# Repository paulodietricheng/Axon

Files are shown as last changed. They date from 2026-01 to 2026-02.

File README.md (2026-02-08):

# Axon

Axon is a single-channel mixed-signal Electromyography (EMG) acquisition and actuation system built around a custom PCB. It combines a low-noise analog front end, delta-sigma analog-to-digital conversion, and STM32 firmware for real-time signal acquisition and control of external devices.

The project emphasizes signal integrity, deterministic signal paths, and hardware/firmware co-design in a timing-constrained embedded system.

## System Architecture
Axon implements a linear signal-processing pipeline from electrodes to digital processing:

- Electrodes  
- Input Protection  
- Instrumentation Amplifier  
- Active Band-Pass Filtering  
- Delta-Sigma ADC  
- STM32 (SPI)  
- Actuation Outputs

## Analog Front End

### Input Protection
- 100 kΩ series resistor at the electrode input
- Schottky diode clamps to +5 V and −5 V
- Protects downstream circuitry from transients and overvoltage events

### Instrumentation Amplifier
- INA333 instrumentation amplifier
- Gain: 20×
- Chosen for high CMRR (~100 dB) to suppress common-mode noise inherent in EMG signals
- Reference voltage provided by a buffered ground generated using an OPA333

### Active Filtering
All active filters use OPA333 op-amps for low offset and low noise.

- High-pass Sallen–Key filter  
  - Cutoff frequency: 15 Hz  
  - Linear gain  
  - Removes DC offset and motion artifacts

- Low-pass Sallen–Key filter  
  - Cutoff frequency: 450 Hz
  - Gain: 5×
  - Limits high-frequency noise and out-of-band content

## Analog-to-Digital Conversion

- ADS131M02 delta-sigma ADC
- Differential inputs:
  - Filtered signal routed through 1 kΩ resistors to AIN0P and AIN1P
  - AIN0N and AIN1N tied to buffered ground
- ADC clock provided by an ASE 8.192 MHz oscillator
- Design considers conversion latency and group delay inherent to delta-sigma architectures

## Digital Processing & Control

### Microcontroller
- STM32 microcontroller
- Communicates with ADC via SPI
- Handles data acquisition, processing, and output control

### Programming & Debug
- JTAG / SWD interface exposed
- Signals:
  - SWDIO, SWCLK, SWO, RESET
  - RXI, TXO
  - VREF = 3.3 V

### Outputs
- Three MCU-controlled output pins routed to an external connector
- Intended for actuation or control of external devices

## Power Architecture

- USB-C power input
- Protection fuse on input
- Power rails:
  - +5 V from USB
  - −5 V generated via TPS7A inverter
  - 3.3 V generated via TPS604 DC-DC converter

## PCB Layout

- 4-layer PCB stackup:
  1. Signal
  2. Ground plane
  3. Power pours
  4. Signal
- Layout prioritizes:
  - Low-noise analog routing
  - Solid ground reference
  - Separation of analog and digital domains

## Notes

Axon serves as a completed mixed-signal system demonstrating practical considerations in low-level analog design, real-time embedded firmware, and end-to-end signal path analysis.

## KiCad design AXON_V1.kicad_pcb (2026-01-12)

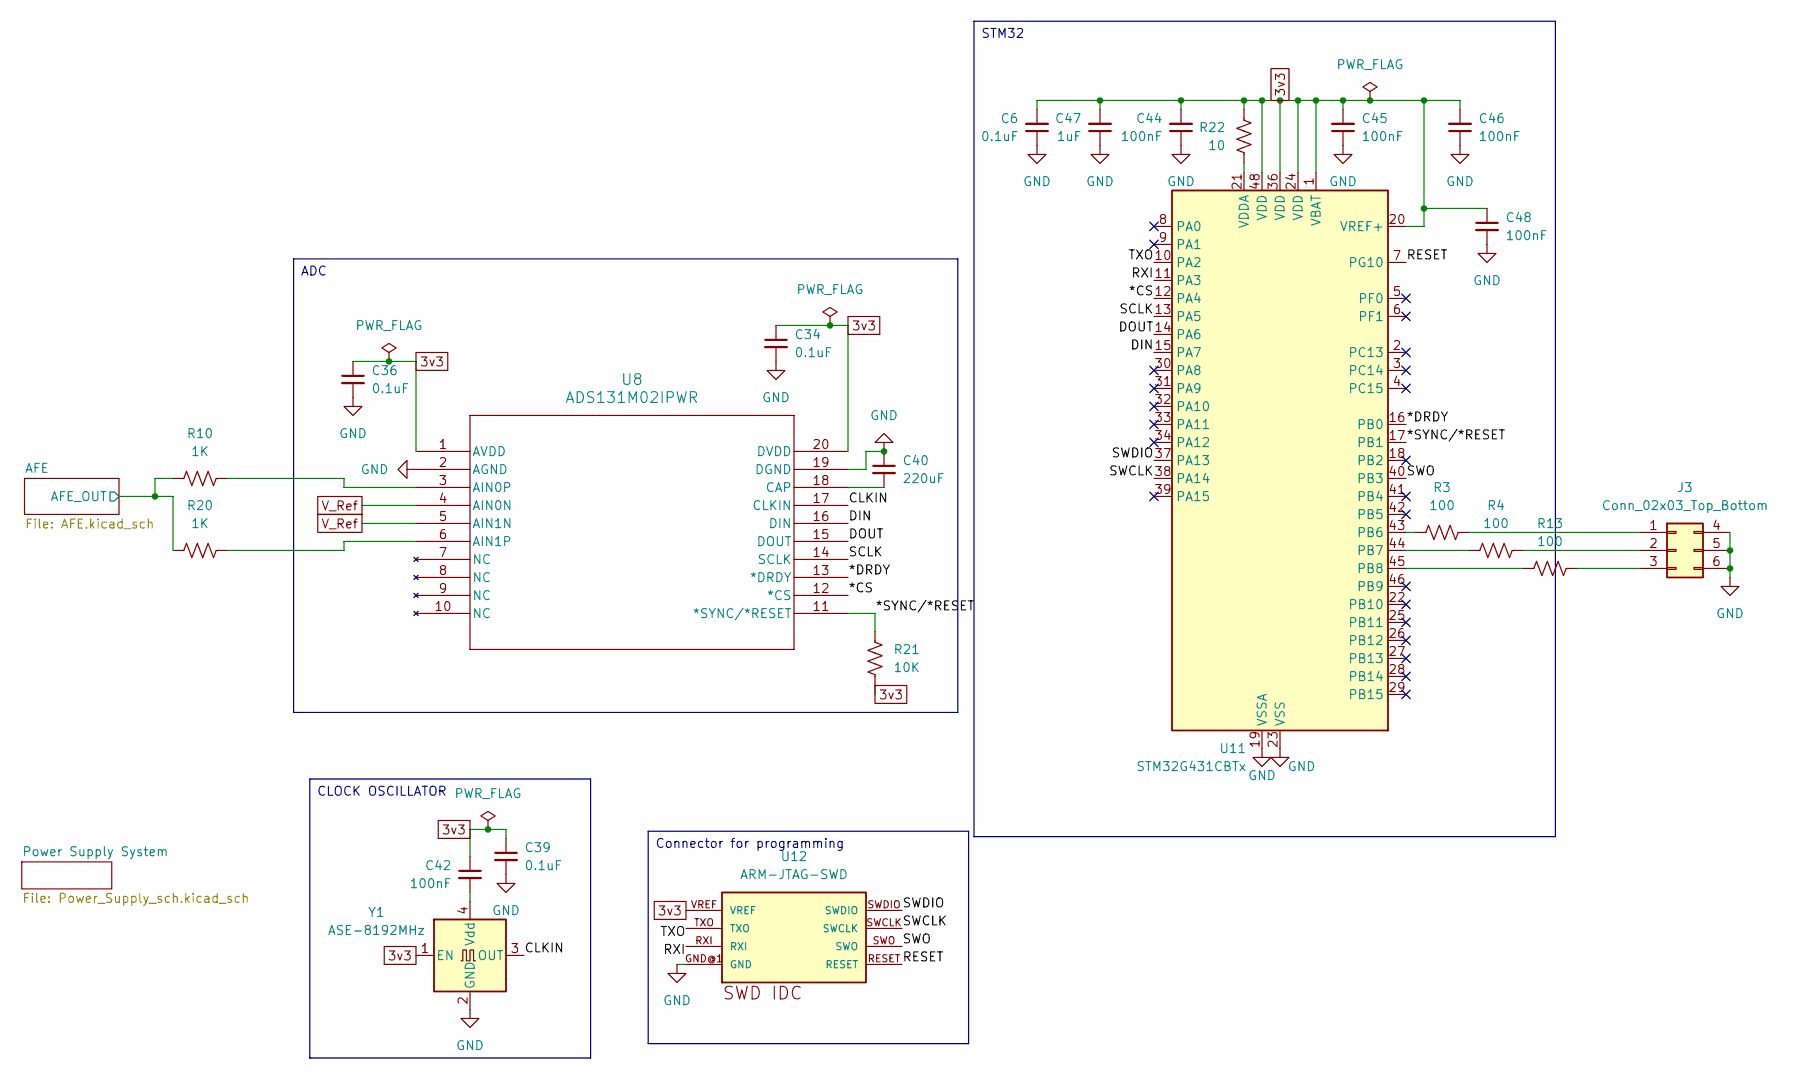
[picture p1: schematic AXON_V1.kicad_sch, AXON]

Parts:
C6, C34, C36, C39: 0.1uF; C_0201_0603Metric
C40: 220uF; C_0201_0603Metric
C42, C44, C45, C46, C48: 100nF; C_0201_0603Metric
C47: 1uF; C_0201_0603Metric
J3: Conn_02x03_Top_Bottom; PinSocket_2x03_P2.54mm_Vertical
R3, R4, R13: 100; R_0201_0603Metric
R10, R20: 1K; R_0201_0603Metric
R21: 10K; R_0201_0603Metric
R22: 10; R_0201_0603Metric
U8: ADS131M02IPWR; TSSOP20_PW_TEX
U11: STM32G431CBTx; LQFP-48_7x7mm_P0.5mm
U12: ARM-JTAG-SWD; ARM-JTAG-10-SWD-IDC
Y1: ASE-8192MHz; Oscillator_SMD_Abracon_ASE-4Pin_3.2x2.5mm

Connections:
3v3: C6.2, C34.1, C36.1, C39.1, C42.1, C44.2, C45.2, C46.2, C47.2, C48.1, R21.2, R22.1, U8.1 (AVDD), U8.20 (DVDD), U11.1 (VBAT), U11.20 (VREF+), U11.24 (VDD), U11.36 (VDD), U11.48 (VDD), U12.VREF, Y1.1 (EN); also elsewhere on the board
/*CS: U8.12 (*CS), U11.12 (PA4)
/*DRDY: U8.13 (*DRDY), U11.16 (PB0)
/*SYNC/*RESET: R21.1, U8.11 (*SYNC/*RESET), U11.17 (PB1)
/AFE/AFE_OUT: R10.1, R20.1; also elsewhere on the board
/CLKIN: U8.17 (CLKIN), Y1.3 (OUT)
/DIN: U8.16 (DIN), U11.15 (PA7)
/DOUT: U8.15 (DOUT), U11.14 (PA6)
/RESET: U11.7 (PG10), U12.RESET
/RXI: U11.11 (PA3), U12.RXI
/SCLK: U8.14 (SCLK), U11.13 (PA5)
/SWCLK: U11.38 (PA14), U12.SWCLK
/SWDIO: U11.37 (PA13), U12.SWDIO
/SWO: U11.40 (PB3), U12.SWO
/TXO: U11.10 (PA2), U12.TXO
GND: C6.1, C34.2, C36.2, C39.2, C40.1, C44.1, C45.1, C46.1, C47.1, C48.2, J3.4, J3.5, J3.6, U8.2 (AGND), U8.19 (DGND), U11.19 (VSSA), U11.23 (VSS), U11.35 (VSS), U11.47 (VSS), U12.GND@1 (GND), U12.GND@2 (GND), U12.GND@3 (GND), Y1.2 (GND); also elsewhere on the board
unnamed: J3.1, R3.2
unnamed: J3.2, R4.2
unnamed: J3.3, R13.2
unnamed: R10.2, U8.3 (AIN0P)
unnamed: R20.2, U8.6 (AIN1P)
unnamed: C40.2, U8.18 (CAP)
unnamed: R3.1, U11.43 (PB6)
unnamed: R4.1, U11.44 (PB7)
unnamed: R13.1, U11.45 (PB8)
unnamed: R22.2, U11.21 (VDDA)
unnamed: C42.2, Y1.4 (Vdd)
V_Ref: U8.4 (AIN0N), U8.5 (AIN1N); also elsewhere on the board

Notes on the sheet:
CLOCK OSCILLATOR
ADC
Connector for programming
STM32

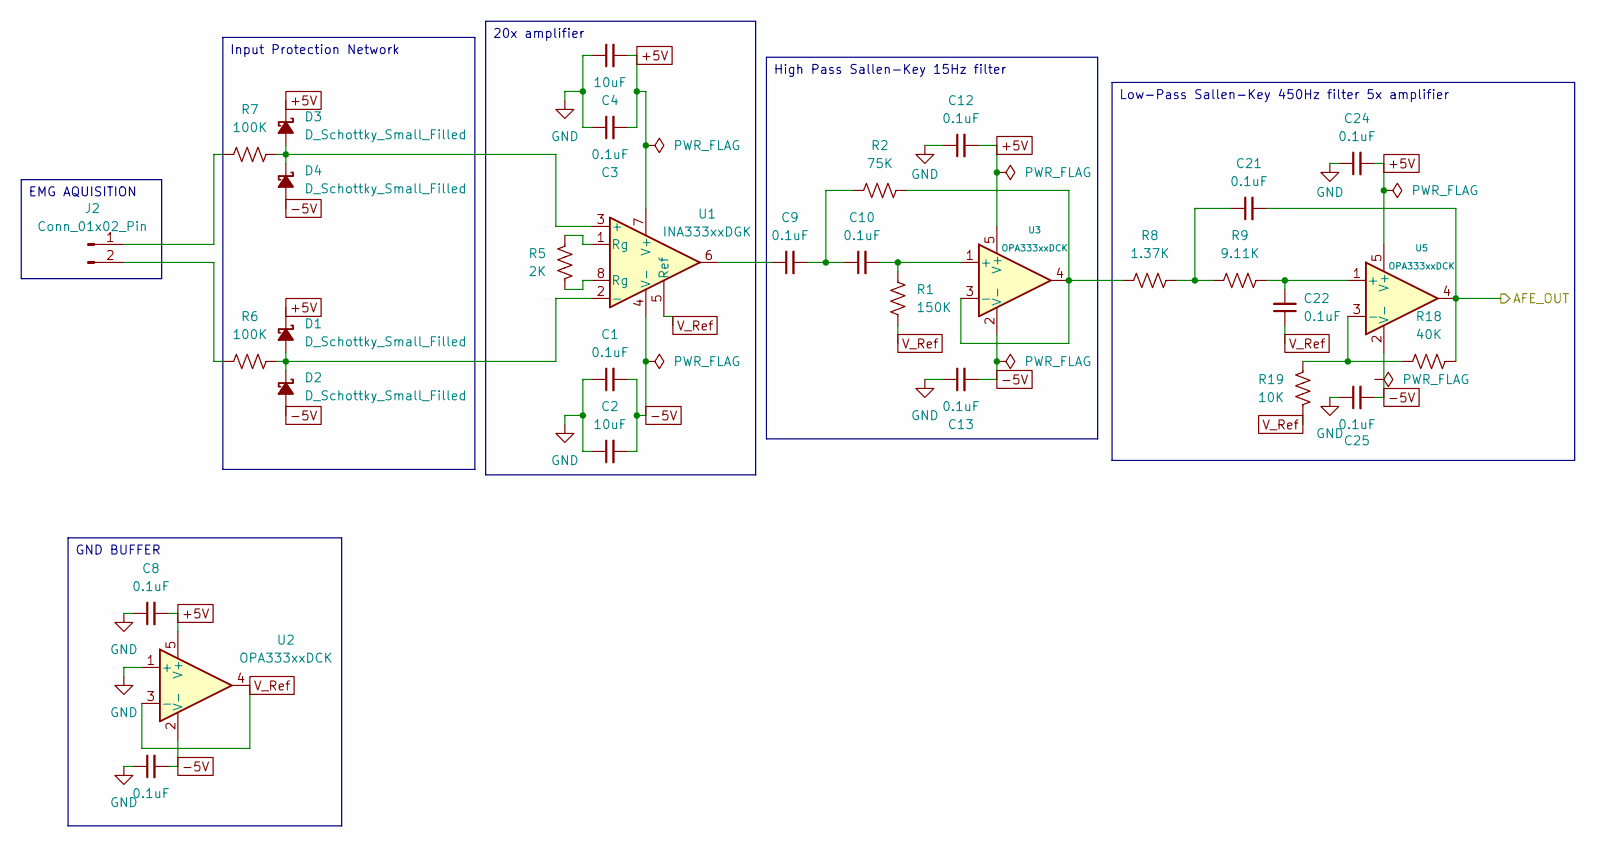
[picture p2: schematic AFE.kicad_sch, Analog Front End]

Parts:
C1, C3, C5, C8, C9, C10, C12, C13, C21, C22, C24, C25: 0.1uF; C_0201_0603Metric
C2, C4: 10uF; C_0201_0603Metric
D1, D2, D3, D4: D_Schottky_Small_Filled; D_0201_0603Metric
J2: Conn_01x02_Pin; JWT_A3963_1x02_P3.96mm_Vertical
R1: 150K; R_0201_0603Metric
R2: 75K; R_0201_0603Metric
R5: 2K; R_0201_0603Metric
R6, R7: 100K; R_0201_0603Metric
R8: 1.37K; R_0201_0603Metric
R9: 9.11K; R_0201_0603Metric
R18: 40K; R_0201_0603Metric
R19: 10K; R_0201_0603Metric
U1: INA333xxDGK; VSSOP-8_3x3mm_P0.65mm
U2, U3, U5: OPA333xxDCK; SOT-353_SC-70-5

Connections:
+5V: C3.2, C4.2, C8.2, C12.2, C24.2, D1.1 (K), D3.1 (K), U1.7 (V+), U2.5 (V+), U3.5 (V+), U5.5 (V+); also elsewhere on the board
-5V: C1.2, C2.2, C5.2, C13.2, C25.2, D2.2 (A), D4.2 (A), U1.4 (V-), U2.2 (V-), U3.2 (V-), U5.2 (V-); also elsewhere on the board
/AFE/AFE_OUT: C21.2, R18.2, U5.4; also elsewhere on the board
GND: C1.1, C2.1, C3.1, C4.1, C5.1, C8.1, C12.1, C13.1, C24.1, C25.1, U2.1 (+); also elsewhere on the board
unnamed: C9.1, U1.6
unnamed: C9.2, C10.1, R2.1
unnamed: C21.1, R8.2, R9.1
unnamed: D1.2 (A), D2.1 (K), R6.2, U1.2 (-)
unnamed: D3.2 (A), D4.1 (K), R7.2, U1.3 (+)
unnamed: J2.1, R7.1
unnamed: J2.2, R6.1
unnamed: R5.1, U1.1 (Rg)
unnamed: R5.2, U1.8 (Rg)
unnamed: C10.2, R1.1, U3.1 (+)
unnamed: R2.2, R8.1, U3.3 (-), U3.4
unnamed: C22.2, R9.2, U5.1 (+)
unnamed: R18.1, R19.1, U5.3 (-)
V_Ref: C22.1, R1.2, R19.2, U1.5 (Ref), U2.3 (-), U2.4; also elsewhere on the board

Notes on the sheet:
High Pass Sallen-Key 15Hz filter
GND BUFFER
Low-Pass Sallen-Key 450Hz filter 5x amplifier
Input Protection Network
20x amplifier
EMG AQUISITION

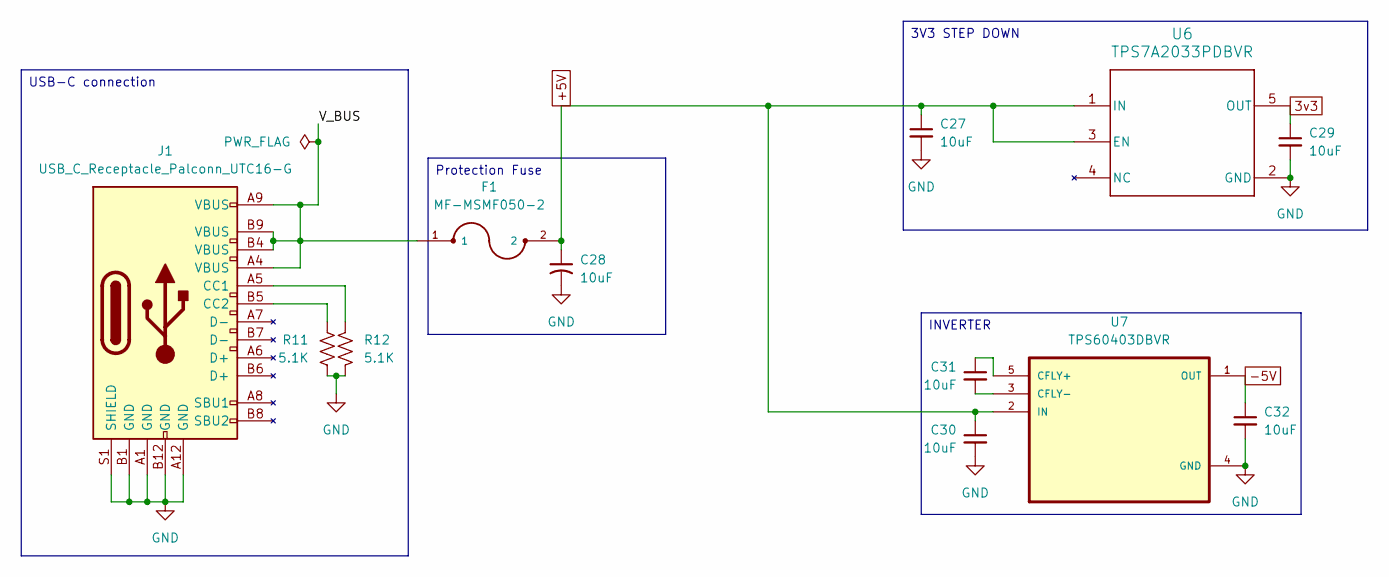
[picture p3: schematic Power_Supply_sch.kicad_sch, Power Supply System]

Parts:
C27, C28, C29, C30, C31, C32: 10uF; C_0201_0603Metric
F1: MF-MSMF050-2; FUSE_F050-2
J1: USB_C_Receptacle_Palconn_UTC16-G
R11, R12: 5.1K; R_0201_0603Metric
U6: TPS7A2033PDBVR; DBV0005A-IPC_A
U7: TPS60403DBVR; SOT95P280X145-5N

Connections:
3v3: C29.1, U6.5 (OUT); also elsewhere on the board
+5V: C27.1, C28.1, C30.1, F1.2, U6.1 (IN), U6.3 (EN), U7.2 (IN); also elsewhere on the board
-5V: C32.1, U7.1 (OUT); also elsewhere on the board
/Power Supply System/V_BUS: F1.1, J1.A4 (VBUS), J1.A9 (VBUS), J1.B4 (VBUS), J1.B9 (VBUS)
GND: C27.2, C28.2, C29.2, C30.2, C32.2, J1.A1 (GND), J1.A12 (GND), J1.B1 (GND), J1.B12 (GND), J1.S1 (SHIELD), R11.2, R12.2, U6.2 (GND), U7.4 (GND); also elsewhere on the board
unnamed: J1.A5 (CC1), R12.1
unnamed: J1.B5 (CC2), R11.1
unnamed: C31.1, U7.5 (CFLY+)
unnamed: C31.2, U7.3 (CFLY-)

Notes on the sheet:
USB-C connection
INVERTER
3V3 STEP DOWN
Protection Fuse

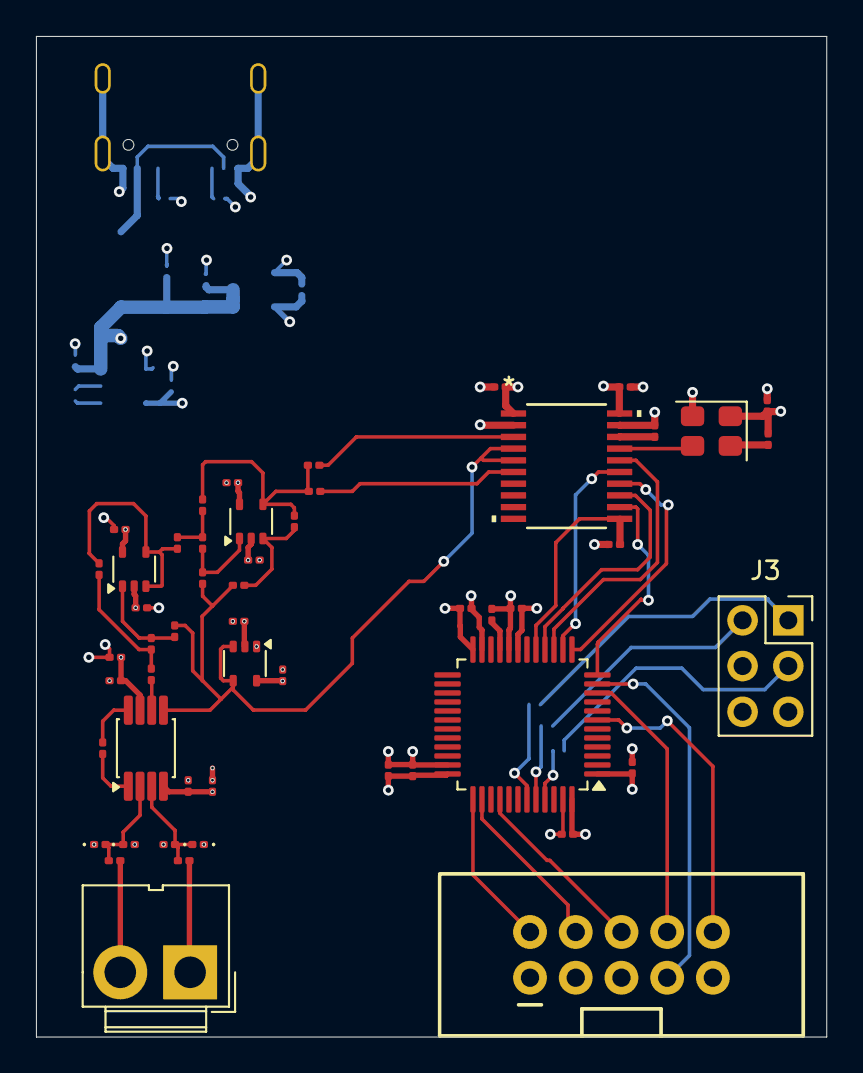
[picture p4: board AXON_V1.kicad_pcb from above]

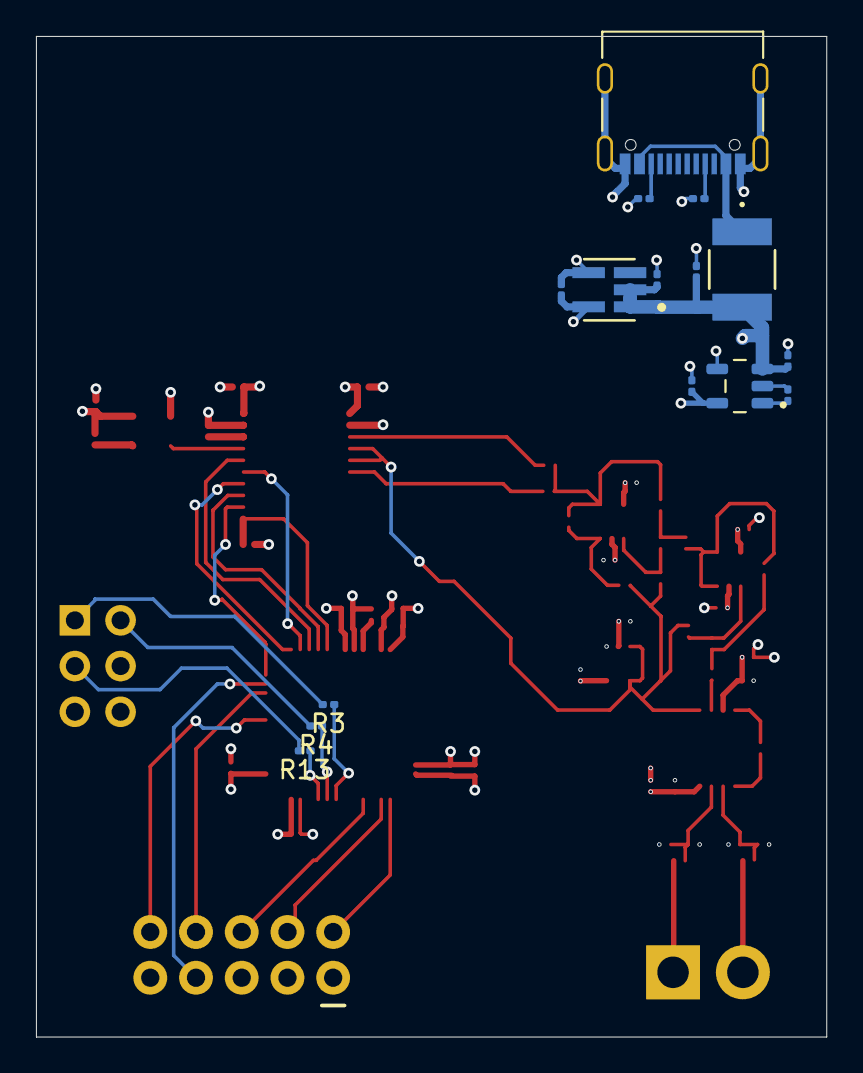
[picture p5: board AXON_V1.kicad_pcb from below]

Board: 4 copper layers, 43.9 x 55.6 mm, 67 parts (15 on the bottom side), 48 nets.
